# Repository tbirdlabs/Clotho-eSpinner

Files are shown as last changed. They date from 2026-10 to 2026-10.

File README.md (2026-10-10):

# Clotho eSpinner

**Clotho** is a 3D-printed eSpinner (electric spinning wheel).
Printable parts, build notes and photos are on Printables:
<https://www.printables.com/model/1779646-clotho-espinner>

This repo holds the CAD files, the foot pedal firmware and the wiring diagram:

- `cad/`: STEP model and 3MF print files
- `firmware/`: PlatformIO project for the foot pedal
- `docs/`: wiring diagram

The pedal has a 10K potentiometer. The firmware reads it and drives a BLD-510B brushless
motor controller with a ~1 kHz PWM speed signal. It has a calibration routine and
adjustable dead zones at the heel and toe ends, and saves both to EEPROM.

## CAD

- `cad/clotho.step`: the full assembly. Open it in any CAD program to modify or remix parts.
- `cad/*.3mf`: PrusaSlicer projects, one per assembly, ready to slice:

  | File | Part |
  |------|------|
  | `base.3mf` | Base |
  | `front-riser-assembly.3mf` | Front riser |
  | `rear-riser-assembly.3mf` | Rear riser |
  | `flyer-assembly.3mf` | Flyer |
  | `bobbin-assembly.3mf` | Bobbin |
  | `spreader-assembly.3mf` | Spreader |
  | `poly-belt-form.3mf` | Poly belt form |
  | `foot-pedal.3mf` | Foot pedal |

The 3MFs are set up for PETG on a Prusa Core One (0.4 mm nozzle, 0.20 mm STRUCTURAL).
On another printer, open them and switch to your own printer and filament profiles.
Build notes and photos are on the Printables page linked above.

## Hardware

- **Board:** SparkFun Pro Micro, **5 V / 16 MHz** (ATmega32U4). The 3.3 V / 8 MHz version
  will not work as configured: the PWM timing assumes 16 MHz.
- **Pot wiper:** A0
- **PWM out:** pin 9 (Timer1 OC1A) to the BLD-510B speed input

Full wiring (v11), in two versions:

- With the foot pedal jack: [docs/clotho_wiring_diagram.svg](docs/clotho_wiring_diagram.svg)
- Without it, with the speed pot wired straight to the driver:
  [docs/clotho_wiring_diagram_no_pedal.svg](docs/clotho_wiring_diagram_no_pedal.svg)

The older diagram on Printables shows EN and F/R tied to +5V. That is wrong. Use these.

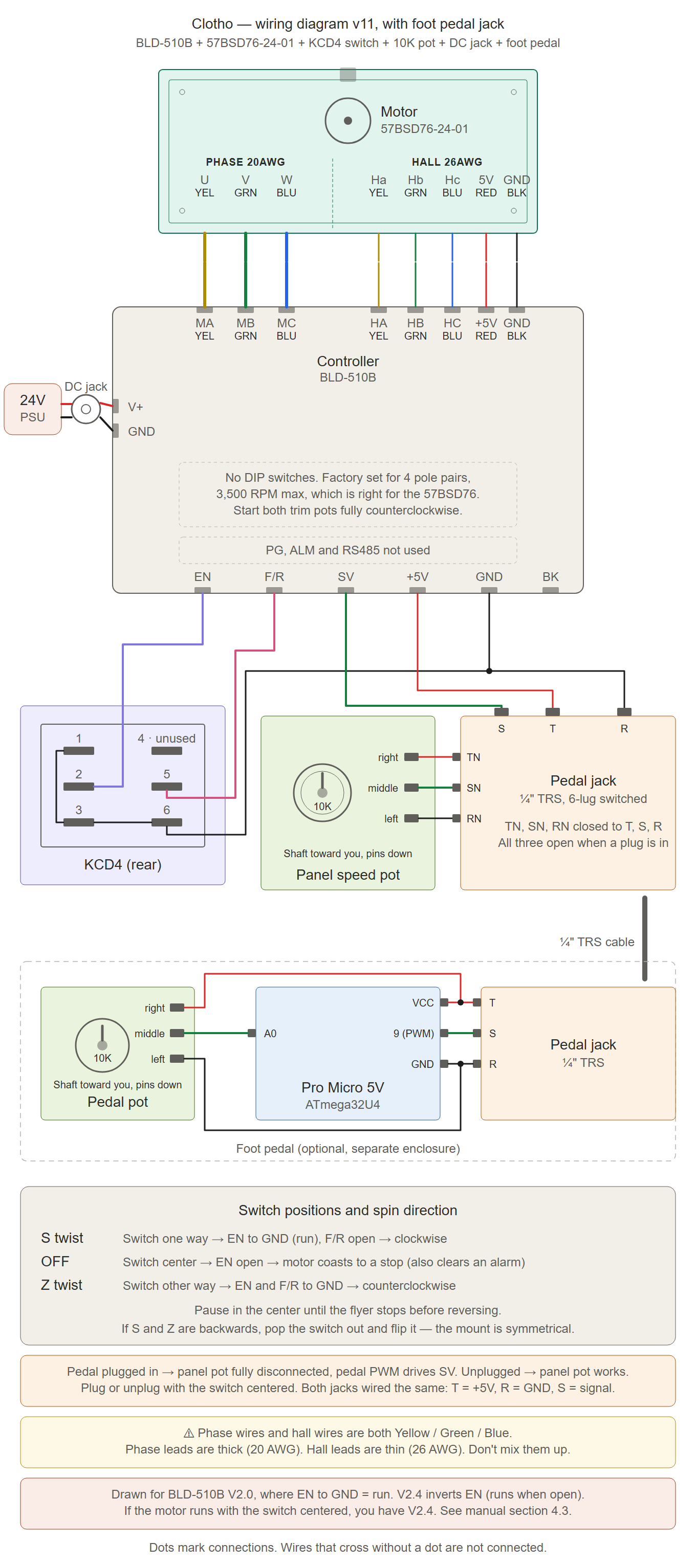
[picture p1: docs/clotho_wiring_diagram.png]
Clotho wiring diagram


## Build and flash

Install [PlatformIO](https://platformio.org/) (VS Code extension or CLI), connect the
Pro Micro by USB, then run these from the `firmware/` folder:

```sh
cd firmware
pio run                     # build
pio run -t upload           # build and flash
pio device monitor -b 9600  # open the serial console
```

In VS Code, open the `firmware/` folder itself so the PlatformIO extension finds the project.

## Serial commands

The serial console runs at 9600 baud. End each command with a newline. Commands are
not case-sensitive.

| Command  | What it does |
|---|---|
| `CAL` | Calibration. Move the pedal through its full range, then type `SAVE` to store the range or `CANCEL` to keep the old one. |
| `DZ` | Dead zones. Asks for the heel-end %, then the toe-end % (each 0–50). Defaults: heel 5, toe 0. |
| `STATUS` | Shows the stored calibration min/max, the dead zones and a live ADC reading. |

Run `CAL` once after flashing. Until you do, the firmware uses the full 0–1023 ADC range.

After power-up, and after leaving `CAL` or `DZ`, the motor stays off until the pedal
returns to rest (inside the heel dead zone). If the pedal is pressed at that point, the
console prints a reminder to release it.

## License

- **Firmware** (`firmware/`): MIT. See [LICENSE](LICENSE).
- **CAD** (`cad/`), **wiring diagram** (`docs/`) and other documentation: CC BY-SA 4.0, the same as
  the Printables listing. See [LICENSE-CC-BY-SA-4.0.txt](LICENSE-CC-BY-SA-4.0.txt).

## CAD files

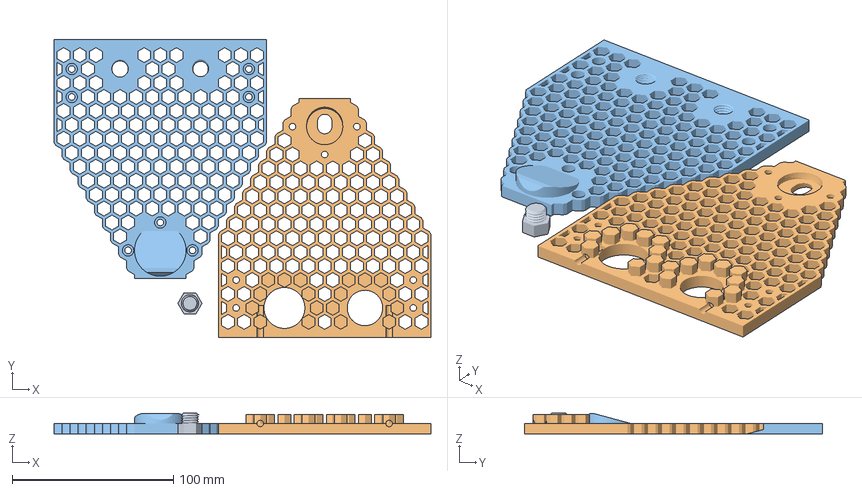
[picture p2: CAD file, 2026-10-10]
cad/rear-riser-assembly.3mf
234.1 x 185.1 x 13.0 mm
Plug
Rear Riser Inner
Rear Riser Outer

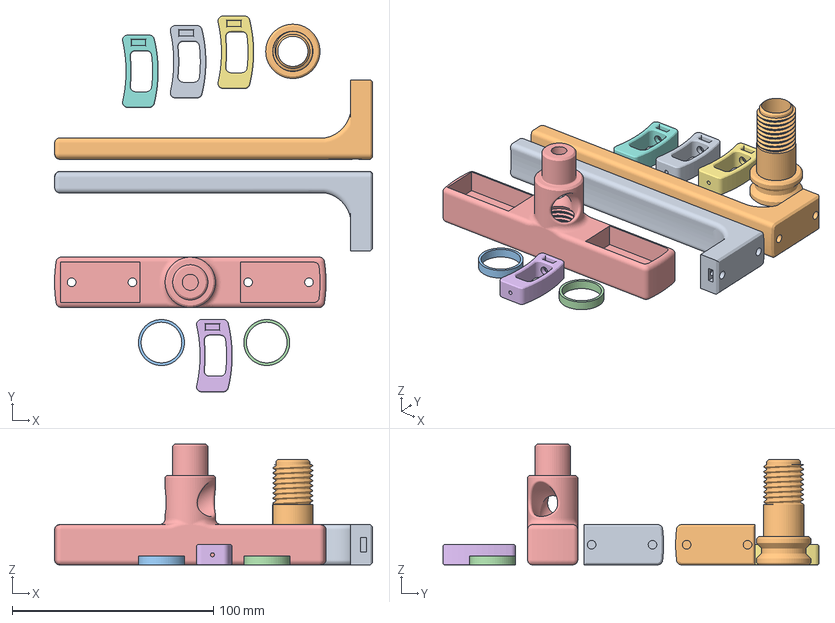
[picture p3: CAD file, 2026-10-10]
cad/flyer-assembly.3mf
158.1 x 186.9 x 60.0 mm
Flyer Arm x 2
Flyer Bearing Spacer
Flyer Body
Hook
Orifice

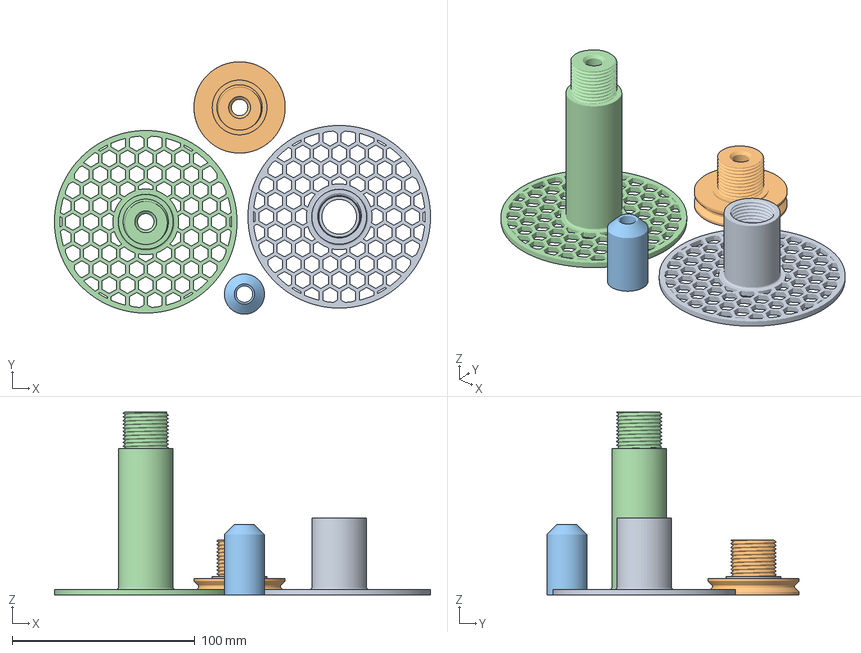
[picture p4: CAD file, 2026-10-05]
cad/bobbin-assembly.3mf
205.9 x 138.2 x 100.0 mm
Front Flange
Rear Bearing Retainer
Rear Bearing Spacer
Rear Flange

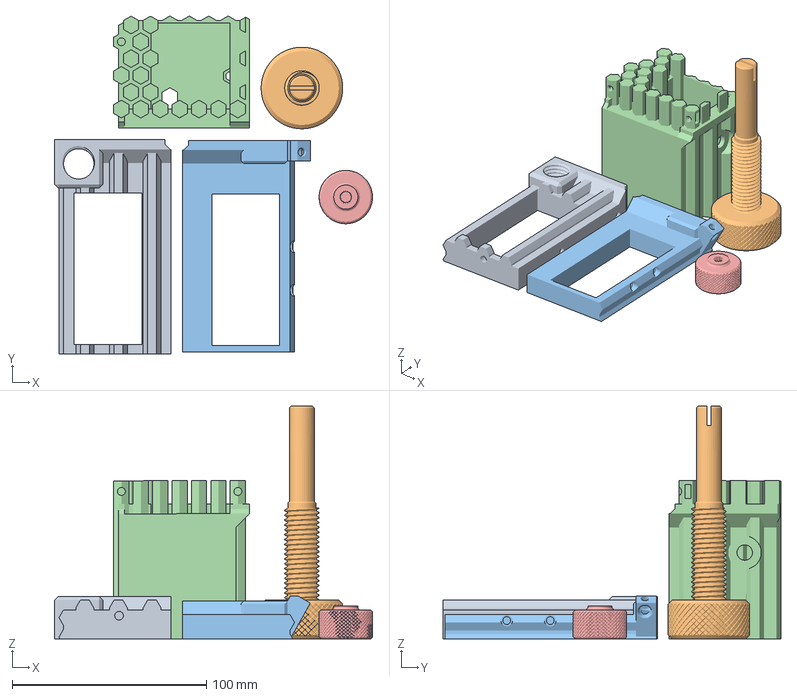
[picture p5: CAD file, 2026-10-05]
cad/spreader-assembly.3mf
163.8 x 174.1 x 120.0 mm
Brake Screw Retainer
Brake Screw
Brake Spring Retainer
Electronics Housing
Speed Control Knob

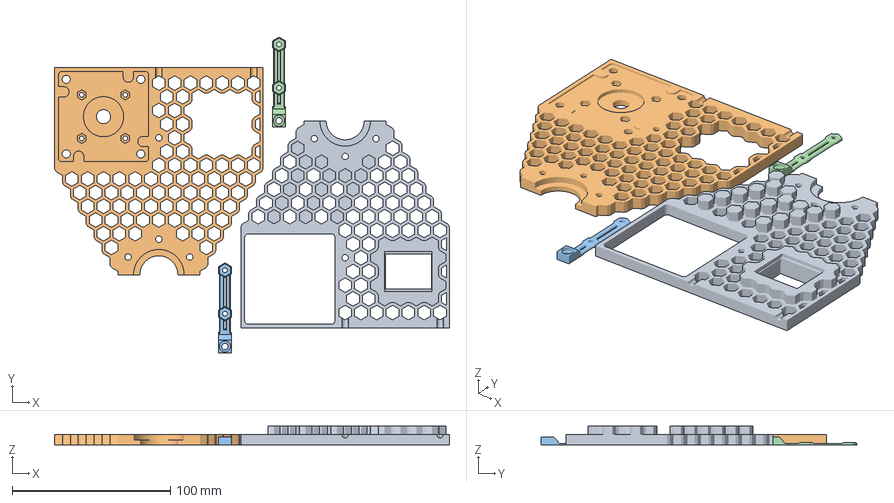
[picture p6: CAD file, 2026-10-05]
cad/front-riser-assembly.3mf
249.8 x 199.6 x 12.0 mm
Front Riser Inner
Front Riser Outer
Motor Bracket x 2

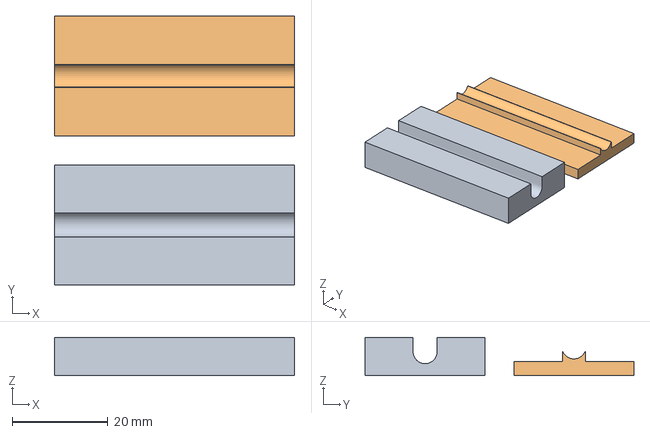
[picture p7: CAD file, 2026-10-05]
cad/poly-belt-form.3mf
50.0 x 56.0 x 8.00 mm
Bottom
Top

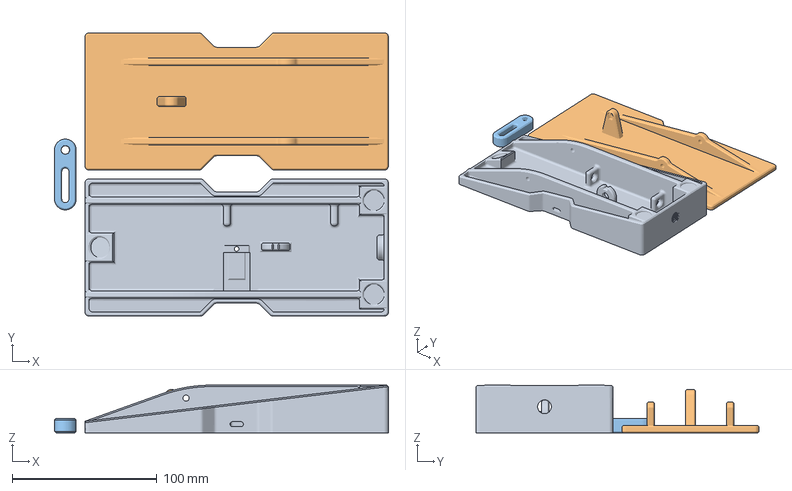
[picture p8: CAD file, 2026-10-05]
cad/foot-pedal.3mf
231.0 x 196.0 x 33.0 mm
Base
Pedal
Yoke

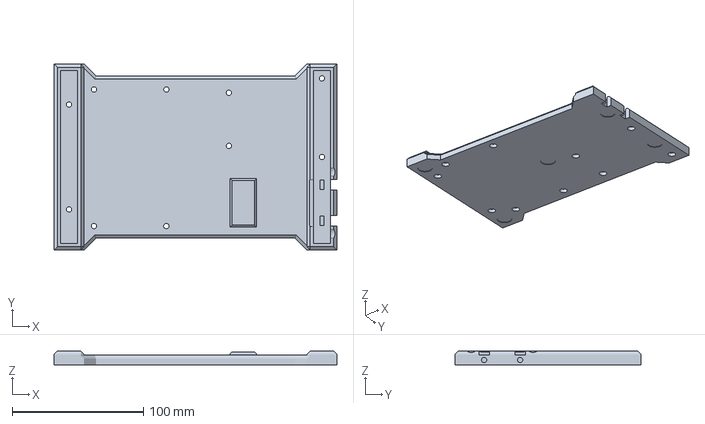
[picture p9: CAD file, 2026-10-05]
cad/base.3mf
216.0 x 142.0 x 10.5 mm

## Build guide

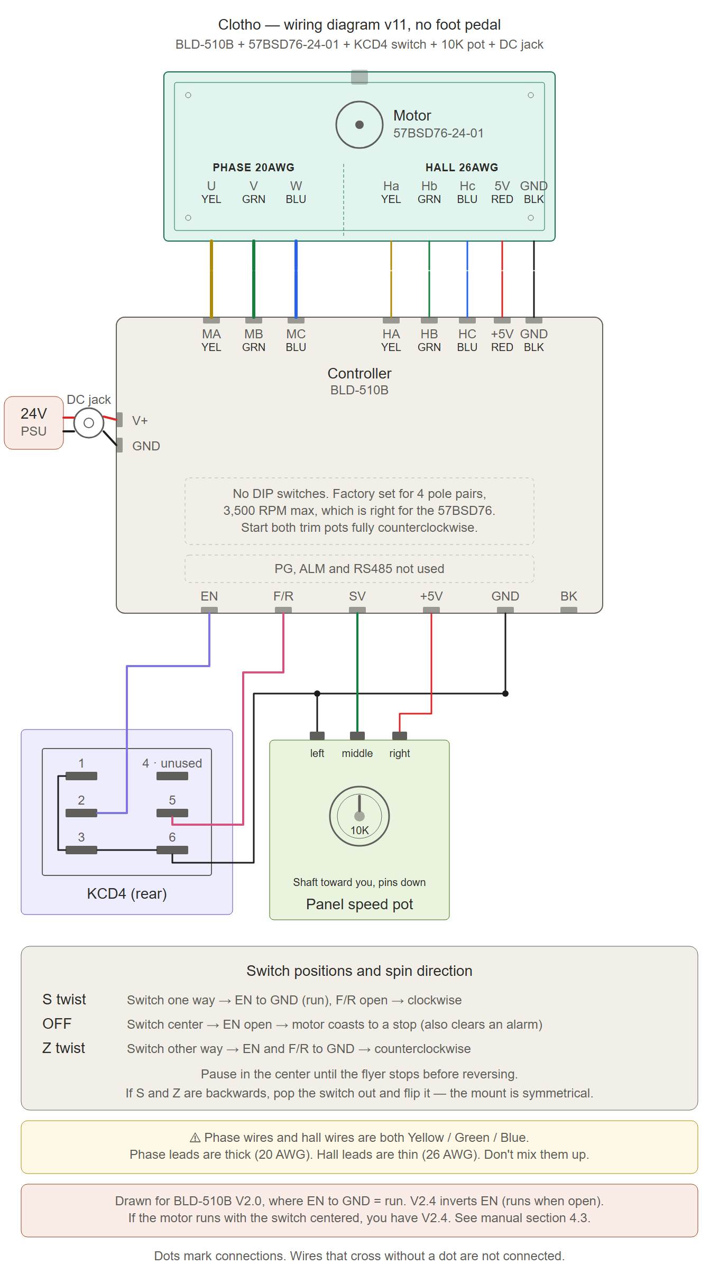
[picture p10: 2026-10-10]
docs/clotho_wiring_diagram_no_pedal.png

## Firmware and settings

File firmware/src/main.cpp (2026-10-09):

/**
 * Clotho Foot Pedal — SparkFun Pro Micro (ATmega32U4, 5 V / 16 MHz)
 *
 * Reads a potentiometer and drives a BLD-510B brushless motor driver
 * via ~1 kHz PWM on Timer1 OC1A (pin 9).
 *
 * Serial commands (9600 baud, newline-terminated):
 *   CAL    — enter calibration mode; sweep pedal full range, then
 *             type SAVE to commit or CANCEL to abort
 *   DZ     — set dead zone percentages (heel end, toe end; each 0–50)
 *   STATUS — print stored cal min/max, dead zones, and live ADC reading
 *
 * EEPROM layout (bytes 0-6):
 *   0-1  uint16  calibrated ADC minimum
 *   2-3  uint16  calibrated ADC maximum
 *   4    uint8   dead zone percentage at heel (bottom) end   (default 5)
 *   5    uint8   dead zone percentage at toe  (top)    end   (default 3, in testing)
 *   6    uint8   magic byte (0xAB = all preceding values valid)
 */

#include <Arduino.h>
#include <EEPROM.h>

// ── Pin assignments ──────────────────────────────────────────────────────────
// Change these constants if you rewire the hardware.
static const uint8_t PIN_POT = A0;  // Potentiometer wiper  (analog input)
static const uint8_t PIN_PWM = 9;   // PWM → BLD-510B signal (Timer1 OC1A)

// ── EEPROM layout ────────────────────────────────────────────────────────────
static const uint16_t EEPROM_ADDR_MIN      = 0;     // 2 bytes — calibrated ADC min
static const uint16_t EEPROM_ADDR_MAX      = 2;     // 2 bytes — calibrated ADC max
static const uint16_t EEPROM_ADDR_DZ_BOT   = 4;     // 1 byte  — heel dead zone %
static const uint16_t EEPROM_ADDR_DZ_TOP   = 5;     // 1 byte  — toe  dead zone %
static const uint16_t EEPROM_ADDR_MAGIC    = 6;     // 1 byte  — validity sentinel
static const uint8_t  EEPROM_MAGIC_VAL     = 0xAB;  // value written when data is valid

// ── Timer1 / PWM settings ────────────────────────────────────────────────────
// Fast PWM, Mode 14 (ICR1 as TOP), prescaler ÷8.
//
//   f_PWM = F_CPU / (prescaler × (ICR1 + 1))
//         = 16 000 000 / (8 × 2 000) = 1 000 Hz
//
// To change frequency:
//   999  → 2 000 Hz
//  1999  → 1 000 Hz   ← default
//  3999  →   500 Hz
static const uint16_t PWM_TOP = 1999;

// ── Calibration ──────────────────────────────────────────────────────────────
// Minimum ADC span (of 1023) CAL will accept.  Rejects a SAVE made before the
// pedal was swept, where ADC noise alone would yield a tiny range and turn the
// pedal into an on/off switch.
static const uint16_t CAL_MIN_RANGE = 100;

// ── Serial input ─────────────────────────────────────────────────────────────
// Longest line kept from the serial console.  Extra characters are dropped so
// a stream of text with no newline can't grow a String until RAM runs out.
static const uint8_t INPUT_MAX_LEN = 16;

// ── Runtime state ────────────────────────────────────────────────────────────
static uint16_t calMin   = 0;
static uint16_t calMax   = 1023;
static uint8_t  dzBottom = 5;   // heel-end dead zone, percent of travel
// The 3% toe default lets the pedal reach full speed without being pressed hard
// against its stop.  Still in testing.  Pedals with saved settings keep theirs;
// only a blank EEPROM picks this up.
static uint8_t  dzTop    = 3;   // toe-end  dead zone, percent of travel
static bool     armed    = false;  // motor enabled only after pedal seen at rest

// ── Forward declarations ─────────────────────────────────────────────────────
static void loadSettings();
static void saveCalibration(uint16_t minVal, uint16_t maxVal);
static void saveDZ(uint8_t bot, uint8_t top);
static void setupTimer1PWM();
static void setDuty(uint8_t duty);
static void runCalibration();
static void runDZ();
static void printStatus();

// =============================================================================
void setup()
{
    // Drive the PWM pin LOW immediately so the BLD-510B's SV input isn't left
    // floating during the USB wait below.  OUTPUT is also required for the
    // Timer1 hardware override to drive the pin later.
    pinMode(PIN_PWM, OUTPUT);

    Serial.begin(9600);

    // ATmega32U4 uses USB-CDC for Serial; wait up to 2 s for host enumeration.
    // If no serial monitor is open the timeout expires and normal operation runs.
    uint32_t t0 = millis();
    while (!Serial && (millis() - t0 < 2000)) { /* wait */ }

    pinMode(PIN_POT, INPUT);

    loadSettings();
    setupTimer1PWM();

    Serial.println(F("Clotho Foot Pedal ready.  Commands: CAL | DZ | STATUS"));
}

// =============================================================================
void loop()
{
    // ── Non-blocking serial command reader ───────────────────────────────────
    // Characters are accumulated until CR or LF, then dispatched as a command.
    static String cmdBuf = "";

    while (Serial.available()) {
        char c = (char)Serial.read();
        if (c == '\n' || c == '\r') {
            cmdBuf.trim();
            if (cmdBuf.length() > 0) {
                cmdBuf.toUpperCase();
                if (cmdBuf == F("CAL")) {
                    runCalibration();
                } else if (cmdBuf == F("DZ")) {
                    runDZ();
                } else if (cmdBuf == F("STATUS")) {
                    printStatus();
                } else {
                    Serial.print(F("Unknown command: "));
                    Serial.println(cmdBuf);
                    Serial.println(F("Valid commands: CAL | DZ | STATUS"));
                }
            }
            cmdBuf = "";
        } else if (cmdBuf.length() < INPUT_MAX_LEN) {
            cmdBuf += c;
        }
    }

    // ── Normal operation: pot reading → PWM duty with dead zones ────────────
    uint16_t adc    = analogRead(PIN_POT);
    uint32_t travel = (calMax > calMin) ? (calMax - calMin) : 0;

    uint16_t dzBotThreshold = calMin + (uint16_t)(travel * dzBottom / 100UL);
    uint16_t dzTopThreshold = calMax - (uint16_t)(travel * dzTop    / 100UL);

    uint8_t duty;
    if (adc <= dzBotThreshold) {
        duty = 0;
    } else if (adc >= dzTopThreshold) {
        duty = 255;
    } else {
        long mapped = map((long)adc,
                          (long)dzBotThreshold, (long)dzTopThreshold,
                          0L, 255L);
        duty = (uint8_t)constrain(mapped, 0, 255);
    }

    // ── Safety interlock ─────────────────────────────────────────────────────
    // After power-up or leaving a menu, hold the motor off until the pedal is
    // seen at rest (inside the heel dead zone), so it never starts on its own.
    static bool warned = false;
    if (!armed) {
        if (duty == 0) {
            armed  = true;
            warned = false;
        } else {
            duty = 0;
            if (!warned) {
                Serial.println(F("Pedal not at rest — release it to enable the motor."));
                warned = true;
            }
        }
    }
    setDuty(duty);
}

// =============================================================================
// loadSettings
//   Read persisted calibration and dead zone values from EEPROM.  If the magic
//   byte is absent (blank EEPROM reads 0xFF) fall back to full defaults.
// =============================================================================
static void loadSettings()
{
    uint8_t magic = EEPROM.read(EEPROM_ADDR_MAGIC);
    if (magic == EEPROM_MAGIC_VAL) {
        EEPROM.get(EEPROM_ADDR_MIN,    calMin);
        EEPROM.get(EEPROM_ADDR_MAX,    calMax);
        dzBottom = EEPROM.read(EEPROM_ADDR_DZ_BOT);
        dzTop    = EEPROM.read(EEPROM_ADDR_DZ_TOP);
        Serial.print(F("Settings loaded — min="));
        Serial.print(calMin);
        Serial.print(F(", max="));
        Serial.print(calMax);
        Serial.print(F(", dzBottom="));
        Serial.print(dzBottom);
        Serial.print(F("%, dzTop="));
        Serial.print(dzTop);
        Serial.println(F("%"));
    } else {
        calMin   = 0;
        calMax   = 1023;
        dzBottom = 5;
        dzTop    = 3;
        Serial.println(F("EEPROM blank — using defaults (min=0, max=1023, dzBottom=5%, dzTop=3%)."));
    }
}

// =============================================================================
// saveCalibration
//   Persist min/max to EEPROM and re-stamp the magic byte.
//   Dead zone bytes are preserved: written back from the current runtime values
//   so the full record remains consistent without disturbing DZ.
//   EEPROM.put() performs update-only writes to reduce cell wear.
// =============================================================================
static void saveCalibration(uint16_t minVal, uint16_t maxVal)
{
    EEPROM.put(EEPROM_ADDR_MIN,   minVal);
    EEPROM.put(EEPROM_ADDR_MAX,   maxVal);
    EEPROM.update(EEPROM_ADDR_DZ_BOT, dzBottom);  // preserve current DZ values
    EEPROM.update(EEPROM_ADDR_DZ_TOP, dzTop);
    EEPROM.write(EEPROM_ADDR_MAGIC, EEPROM_MAGIC_VAL);
    calMin = minVal;
    calMax = maxVal;
}

// =============================================================================
// saveDZ
//   Persist dead zone percentages to EEPROM and re-stamp the magic byte.
//   Calibration bytes are preserved from current runtime values.
// =============================================================================
static void saveDZ(uint8_t bot, uint8_t top)
{
    EEPROM.put(EEPROM_ADDR_MIN,   calMin);   // preserve current cal values
    EEPROM.put(EEPROM_ADDR_MAX,   calMax);
    EEPROM.update(EEPROM_ADDR_DZ_BOT, bot);
    EEPROM.update(EEPROM_ADDR_DZ_TOP, top);
    EEPROM.write(EEPROM_ADDR_MAGIC, EEPROM_MAGIC_VAL);
    dzBottom = bot;
    dzTop    = top;
}

// =============================================================================
// setupTimer1PWM
//   Configure Timer1 for Fast PWM, Mode 14 (ICR1 as TOP) on OC1A (pin 9).
//
//   Register breakdown:
//     TCCR1A  COM1A1=1, COM1A0=0  non-inverting output on OC1A
//             WGM11=1             Fast PWM / ICR1 as TOP (bit 1 of WGM)
//     TCCR1B  WGM13=1, WGM12=1   Fast PWM / ICR1 as TOP (bits 3-2 of WGM)
//             CS11=1              ÷8 prescaler
//
//   Resulting frequency: 16 MHz / (8 × 2 000) = 1 000 Hz
//   PWM resolution: log2(2000) ≈ 11 bits
// =============================================================================
static void setupTimer1PWM()
{
    TIMSK1 = 0;         // disable Timer1 interrupts (none required here)

    ICR1  = PWM_TOP;    // set period / TOP value
    OCR1A = 0;          // initial duty = 0 % (motor off)

    // Fast PWM, non-inverting on OC1A, ÷8 prescaler — see register breakdown above
    TCCR1A = _BV(COM1A1) | _BV(WGM11);
    TCCR1B = _BV(WGM13)  | _BV(WGM12) | _BV(CS11);
}

// =============================================================================
// setDuty
//   Convert an 8-bit duty value (0–255) to a Timer1 compare value and write
//   it to OCR1A.
//
//   Scaling: OCR1A = duty × (PWM_TOP + 1) / 256
//   The >> 8 replaces the /256 division with a fast right-shift.
// =============================================================================
static void setDuty(uint8_t duty)
{
    OCR1A = ((uint32_t)duty * (PWM_TOP + 1UL)) >> 8;
}

// =============================================================================
// runCalibration
//   Interactive calibration mode.
//
//   Streams "ADC: <value>  [<obsMin>-<obsMax>]" at 10 Hz while the user
//   sweeps the pedal through its full mechanical range.  Then:
//     SAVE    — validate and commit observed min/max to EEPROM, then return
//     CANCEL  — discard and return without changing stored calibration
// =============================================================================
static void runCalibration()
{
    setDuty(0);      // motor off while in menu (this function blocks)
    armed = false;   // require pedal at rest before the motor runs again
    Serial.println(F("--- CAL MODE ---"));
    Serial.println(F("Sweep pedal through full range.  Type SAVE or CANCEL."));

    uint16_t obsMin    = 1023;
    uint16_t obsMax    = 0;
    String   input     = "";
    uint32_t lastPrint = millis();

    while (true) {
        uint16_t adc = analogRead(PIN_POT);

        // Continuously track the extremes observed since CAL started
        if (adc < obsMin) obsMin = adc;
        if (adc > obsMax) obsMax = adc;

        // Print live reading at ~10 Hz to avoid flooding the serial buffer
        uint32_t now = millis();
        if (now - lastPrint >= 100UL) {
            lastPrint = now;
            Serial.print(F("ADC: "));
            Serial.print(adc);
            Serial.print(F("  ["));
            Serial.print(obsMin);
            Serial.print(F("-"));
            Serial.print(obsMax);
            Serial.println(F("]"));
        }

        // Accumulate characters; act on CR/LF
        while (Serial.available()) {
            char c = (char)Serial.read();
            if (c == '\n' || c == '\r') {
                input.trim();
                input.toUpperCase();

                if (input == "SAVE") {
                    if (obsMax < obsMin + CAL_MIN_RANGE) {
                        // Pedal never moved, or not swept through its full range
                        Serial.print(F("ERROR: range too narrow (need "));
                        Serial.print(CAL_MIN_RANGE);
                        Serial.println(F("+ counts) — keep sweeping before SAVE."));
                    } else {
                        saveCalibration(obsMin, obsMax);
                        Serial.print(F("Saved — min="));
                        Serial.print(calMin);
                        Serial.print(F(", max="));
                        Serial.println(calMax);
                        Serial.println(F("--- CAL END ---"));
                        return;
                    }
                } else if (input == "CANCEL") {
                    Serial.println(F("Calibration cancelled — previous values unchanged."));
                    Serial.println(F("--- CAL END ---"));
                    return;
                } else if (input.length() > 0) {
                    Serial.println(F("Type SAVE or CANCEL."));
                }
                input = "";
            } else if (input.length() < INPUT_MAX_LEN) {
                input += c;
            }
        }
    }
}

// =============================================================================
// runDZ
//   Interactive dead zone configuration.
//
//   Prompts for bottom (heel) dead zone percentage, then top (toe) dead zone
//   percentage.  Each must be in the range 0–50.  On valid input the values
//   are saved to EEPROM and take effect immediately.
// =============================================================================
static void runDZ()
{
    setDuty(0);      // motor off while in menu (this function blocks)
    armed = false;   // require pedal at rest before the motor runs again
    // Drain any trailing CR/LF left in the serial buffer from the "DZ\r\n"
    // command that invoked us.  At 9600 baud a byte arrives in ~1 ms; 5 ms is
    // enough for the paired byte to land before we peek at the buffer.
    delay(5);
    while (Serial.available()) {
        char c = (char)Serial.peek();
        if (c == '\n' || c == '\r') Serial.read();
        else break;
    }

    // ── Helper lambda equivalent: block until a complete line is received ────
    // Returns the trimmed, upper-cased line.
    auto readLine = []() -> String {
        String buf = "";
        while (true) {
            while (!Serial.available()) { /* spin */ }
            char c = (char)Serial.read();
            if (c == '\n' || c == '\r') {
                // Consume the paired CR or LF of a \r\n / \n\r sequence so
                // the next readLine() call does not see a spurious empty line.
                delay(2);  // ~2 ms — enough for the paired byte to arrive at 9600 baud
                if (Serial.available()) {
                    char next = (char)Serial.peek();
                    if (next == '\n' || next == '\r') Serial.read();
                }
                buf.trim();
                return buf;
            }
            if (buf.length() < INPUT_MAX_LEN) buf += c;
        }
    };

    // ── Parse a dead zone percentage ─────────────────────────────────────────
    // Returns 0–50 for a whole number in range, or -1 for anything else
    // (non-digits, too many digits, or out of range).  toInt() alone would
    // silently turn "x" into 0 and "10abc" into 10.
    auto parsePercent = [](const String &s) -> long {
        if (s.length() == 0 || s.length() > 2) return -1;
        for (unsigned int i = 0; i < s.length(); i++) {
            if (!isDigit(s[i])) return -1;
        }
        long v = s.toInt();
        return (v <= 50) ? v : -1;
    };

    // ── Bottom dead zone ─────────────────────────────────────────────────────
    Serial.print(F("Enter bottom (heel) dead zone % [0-50], current="));
    Serial.print(dzBottom);
    Serial.println(F(":"));

    String line = readLine();
    if (line.length() == 0) {
        Serial.println(F("DZ cancelled."));
        return;
    }
    long newBot = parsePercent(line);
    if (newBot < 0) {
        Serial.println(F("ERROR: enter a whole number 0–50.  DZ cancelled."));
        return;
    }

    // ── Top dead zone ────────────────────────────────────────────────────────
    Serial.print(F("Enter top (toe) dead zone % [0-50], current="));
    Serial.print(dzTop);
    Serial.println(F(":"));

    line = readLine();
    if (line.length() == 0) {
        Serial.println(F("DZ cancelled."));
        return;
    }
    long newTop = parsePercent(line);
    if (newTop < 0) {
        Serial.println(F("ERROR: enter a whole number 0–50.  DZ cancelled."));
        return;
    }

    saveDZ((uint8_t)newBot, (uint8_t)newTop);

    Serial.print(F("Dead zones saved — bottom="));
    Serial.print(dzBottom);
    Serial.print(F("%, top="));
    Serial.print(dzTop);
    Serial.println(F("%"));
}

// =============================================================================
// printStatus
//   Report stored calibration bounds, dead zone settings, and live ADC reading.
// =============================================================================
static void printStatus()
{
    uint16_t adc = analogRead(PIN_POT);
    Serial.print(F("Cal min="));
    Serial.print(calMin);
    Serial.print(F(", max="));
    Serial.print(calMax);
    Serial.print(F(" | dzBottom="));
    Serial.print(dzBottom);
    Serial.print(F("%, dzTop="));
    Serial.print(dzTop);
    Serial.print(F("% | Live ADC="));
    Serial.println(adc);
}

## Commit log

2026-10-05 Stop motor while in CAL and DZ menus
    runCalibration() and runDZ() block until the user finishes, so the motor stayed at its last duty the whole time. Set duty to 0 on entry.
2026-10-05 Drive PWM pin low at startup
    Pin 9 floated during the 2 s USB wait, leaving the BLD-510B SV input undriven. Set it to OUTPUT (LOW) first thing in setup().
2026-10-05 Set a minimum span for CAL (default 100 ADC counts)
    Prevents CAL from accepting too small a range and becoming an on/off switch. Change CAL_MIN_RANGE if necessary.
    [main.cpp]
2026-10-05 Treat CAD files as binary
    STEP is plain text with CRLF line endings, so core.autocrlf=input would rewrite it on commit and git would try to diff 30 MB of geometry. Mark STEP, 3MF and F3D as binary so they are stored byte-for-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
2026-10-05 Add STEP model of the full assembly
    cad/clotho.step, exported from Fusion. The same file as the Printables download.
2026-10-05 Add 3MF print files
    PrusaSlicer projects for each assembly, the same files as the Printables download. Set up for PETG on a Prusa Core One (0.4 mm nozzle).
    [base.3mf, bobbin-assembly.3mf, flyer-assembly.3mf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]
2026-10-05 Add CAD section to README
    List the STEP model and 3MF files, and note the slicer profile they were set up with.
2026-10-05 Hold motor off until pedal is at rest
    After power-up, or on leaving CAL or DZ, the motor ran at whatever the pedal read, so a pressed pedal started it immediately (for example, typing SAVE with the foot at the toe end). Keep duty at 0 un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
2026-10-10 Wiring diagram v11, with and without the foot pedal jack
    - The BLD-510B has no DIP switches; the note now says it's factory set
    for 4 pole pairs and 3,500 RPM and to start both trim pots fully CCW.
    - Terminal names match the manual: EN (not ENA), and GND on the power
    connector (not V-).
    - Pot pins are labeled right/middle/left (shaft toward you, pins down),
    matching the build guide, instead of maker-dependent numbers.
    - New no-pedal version wires the panel pot straight to the driver.
    - Motor label no longer sits on the shaft circle.
2026-10-10 Flyer assembly 3MF with all four hooks
    [flyer-assembly.3mf]
2026-10-10 Rear riser assembly 3MF with the jack plug for builds without the pedal
    [rear-riser-assembly.3mf]
